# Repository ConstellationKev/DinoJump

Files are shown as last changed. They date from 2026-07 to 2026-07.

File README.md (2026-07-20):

# Dino Jump: Mechanical Dinosaur Game
See our demo video [here](https://youtu.be/Z2IjySYvM9o?si=r-w-ZcUsuN7d3cY8)

# Event Photos





## Zine:

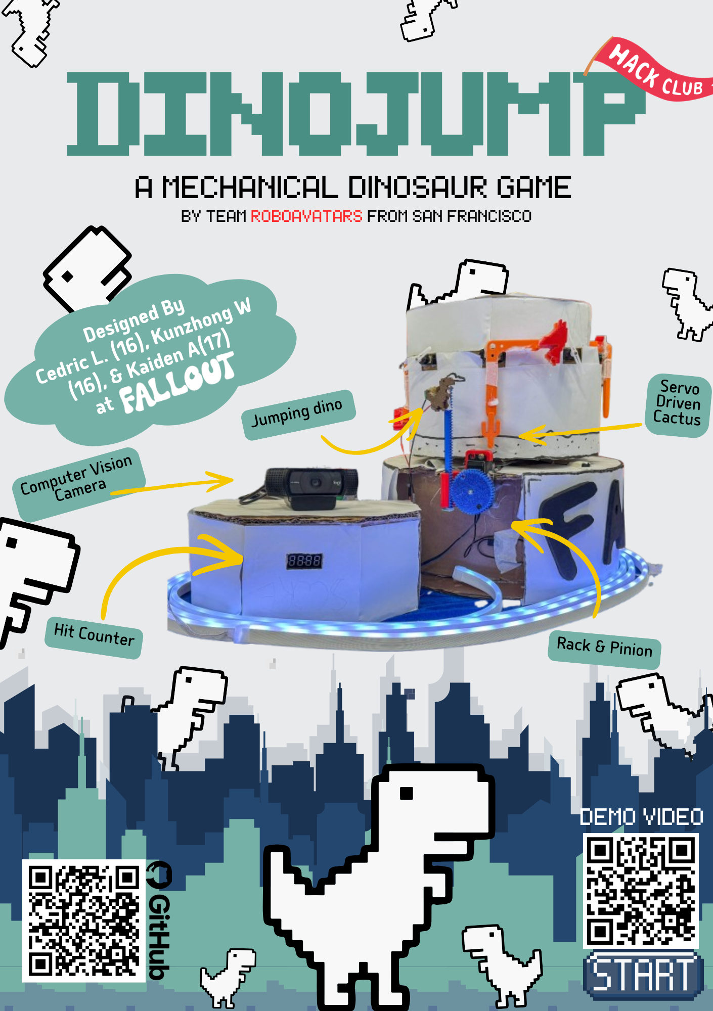
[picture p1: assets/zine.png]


## Why?
### It's 2026, the world has just ended shortly following the Fallout Hackathon...
Within weeks, Canned Wifi supplies have ran out. People have no choice but to the play the classic Chrome Dinosaur game that pops up without internet access.

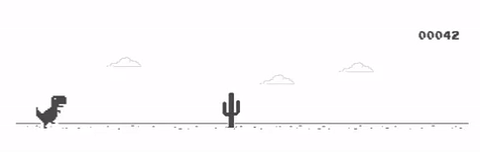
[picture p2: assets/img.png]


We wanted to focus on making a **mechanical version of the game** that relies on **hardware components and physical interaction** rather than heavy software. For this reason, we wanted the Dinosaur to physically interact with the obstacles.

Keeping in mind a focus on physicality (and to make the game more fun) the game is **controlled by a person's physical movement (Jumping/Standing/Crouching)**.

Also, the lack of stable wifi at the venue heavily inspired our idea.

## How?

### 1. The Obstacles:
- The Obstacles are mounted to a large circular disc (a Carousel) **powered directly by a small DC motor.**
- The motor **spins to send obstacles** to the Dinosaur.
- The obstacles are mounted to 4-8 servos, which **randomize the obstacles by either flipping to a** **Cactus, Bird, or nothing.**
- A **small limit switch mounted to the bottom of the carousel**, which brushes up against carefully placed foam bumps, **tells the obstacles when to randomize** their position.

### 2. The Dinosaur
- A **small rack and pinion** assembly moves the stationary Dinosaur up and down
- A small pin allows the dinosaur to **physically touch the obstacles**
- A limit switch pressed up against the Dinosaur **detects hits against the obstacles** when the Dinosaur is physically hit

### 3. Computer Vision
- Mediapipe detects the **position of body limbs**
- OpenCV **processes the camera input**
- **Serial connection** to an ESP32 controls the rack and pinion.

### 4. Electronics
- Since the Carousel is rotating on the base, **there can be no wires that are shared between the two.**
- **The Carousel**
  - The Carousel is powered by Quadruple AA battery pack that supplies 6V to the motor and servos.
  - We use a linear voltage regulator to step down to 3.3V for the ESP32.
  - The DC motor runs on a DRVAA33, and servos run on a PCA9685.
  - A limit switch localizes the position of the carousel to ensure that the obstacles randomize when not facing the user.
- **The Base**
  - The Base is powered by a 5V wall adapter.
  - An powers the rack and pinion, connected to another PCA9685.
  - ESP32 recieves Serial commands ("Standing", "Jumping", "Squatting").

## Assembly
- **You may assemble each component in any order**.
- ### The Base
  - Cut two 12in. diameter cardboard circles.
  - On one of the circles, mount the with zipties.
  - Build a central cylinder that is taller than 140mm.
  - Glue the circles to the ends of the cylinder.
  - Cut the top circle to mount the rack and pinion assembly as shown:
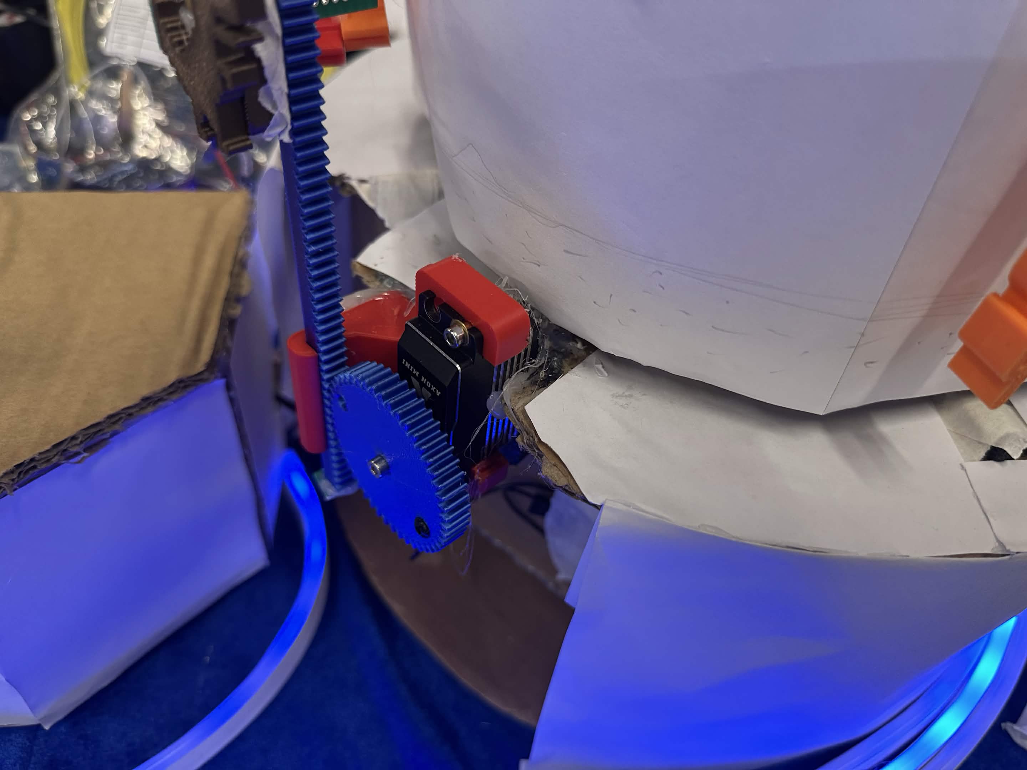
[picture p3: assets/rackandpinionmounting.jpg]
  
  - Attach 4 foam bumpers such that they hit the limit switch every 2 servos, as shown:
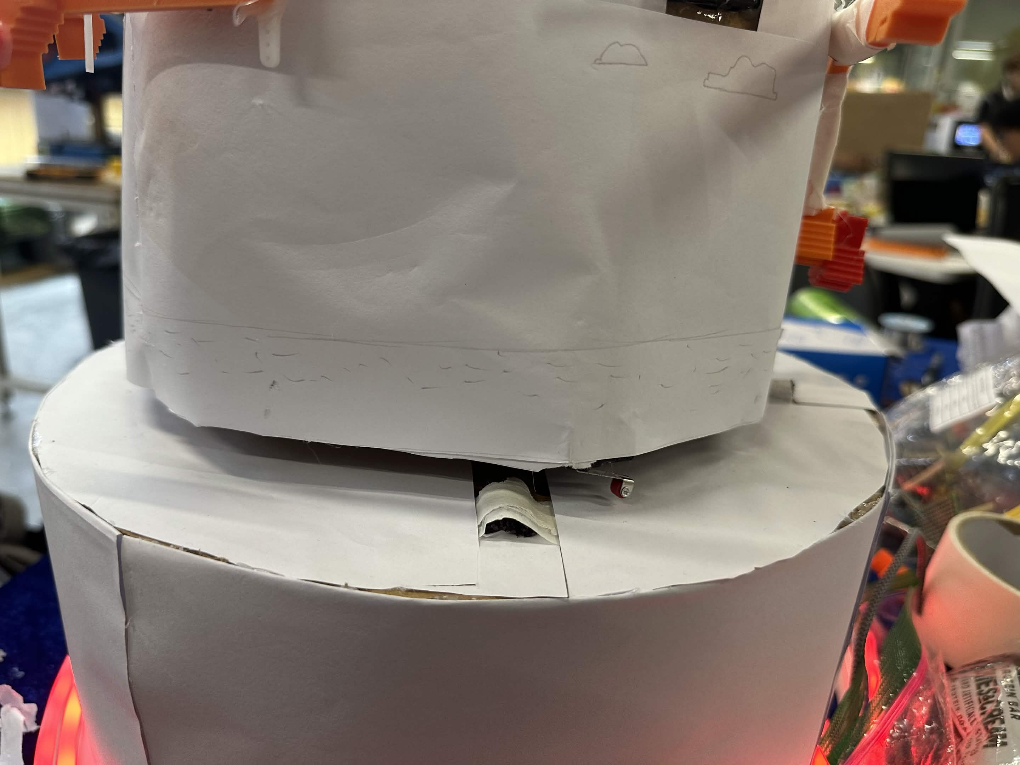
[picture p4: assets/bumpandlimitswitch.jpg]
  - 
- ### The Carousel
  - Cut 8 cardboard strips which are roughly 220mm by 110mm. Fold a 70mm section, followed by a 60mm section, a 30mm section, and another 60mm section. It should look like:

    | 70mm    | 60mm | 30mm | 60mm |
    |---------|------|----|------|
  - Fold the strips into trapezoids, with the 70mm and 30mm sides being parallel. Assemble as shown
  - Cut out slots for servos, as shown:
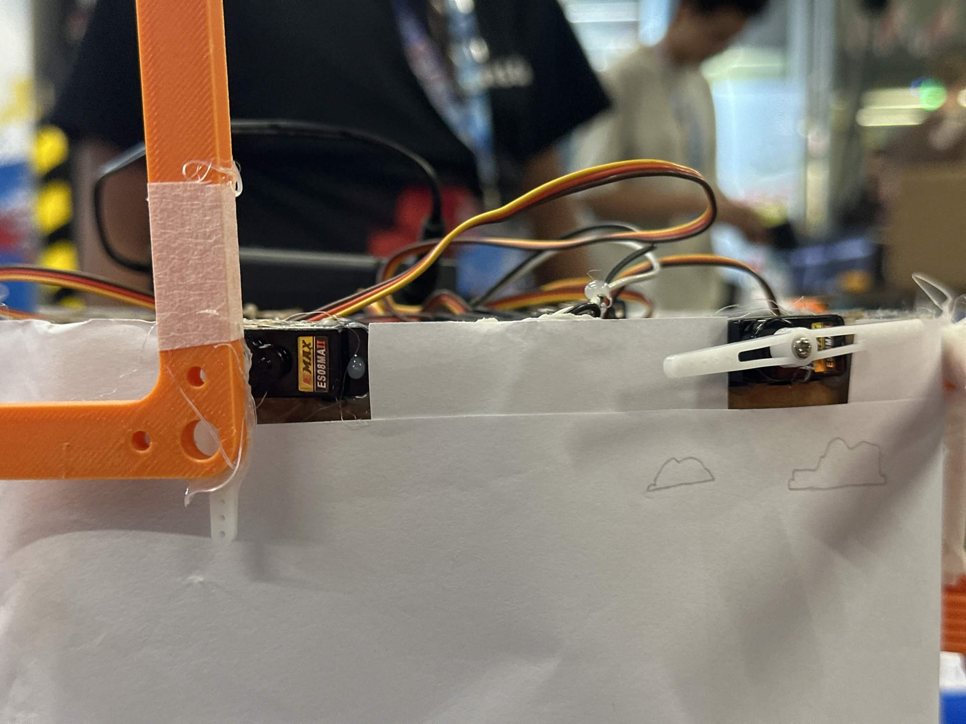
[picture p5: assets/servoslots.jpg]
  
  - Assemble the octagon with hot glue and tape. Take your time!
  - Attach the obstacles to the servos using the servo horn
  - Cut a circle roughly 10in. in diameter, it should be the same diameter as the octagon
  - Mount the motor and mount using zipties and M3 screws
  - Follow the wiring diagram (wire before final assembly)
  - Mount the circle and octagon with hot glue
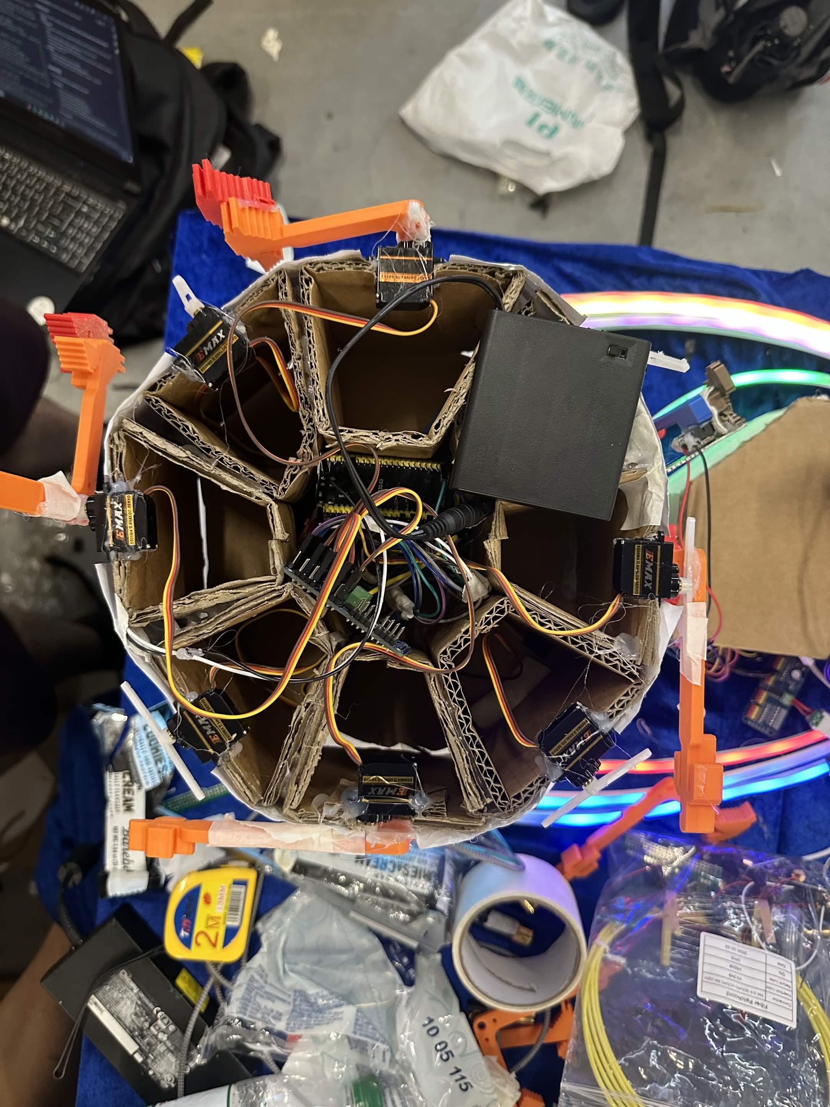
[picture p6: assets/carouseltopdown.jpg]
  

## Software
- Flash corresponding sketches to each ESP32 S3 using Arduino IDE
- If you do not get a serial output/input, try changing the USB CDC setting

## Usage
- Power the Base by plugging in the wall connector
- Start vision.py and follow on screen cailbration
- Position the 0 servo next to the limit switch bump
- Power the Carousel by turning on the battery

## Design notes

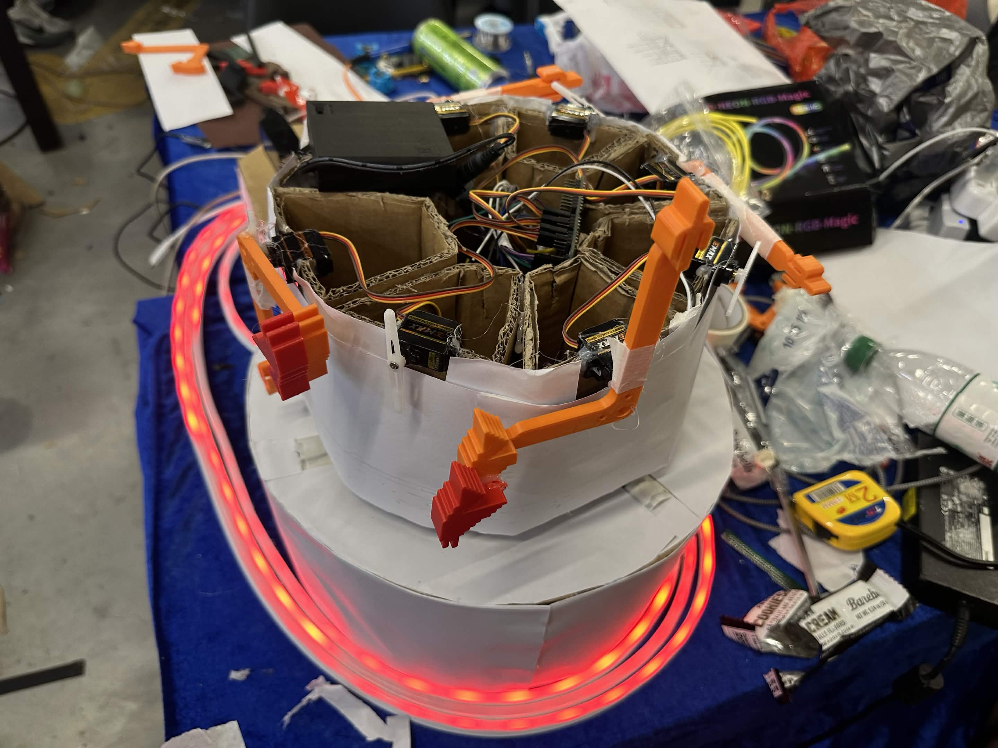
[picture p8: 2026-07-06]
assets/normalviewcarousel.jpg

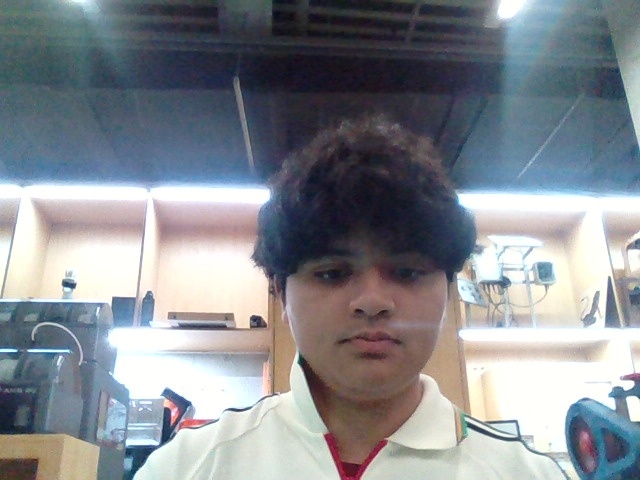
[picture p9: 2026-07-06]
firmware_base/image.jpg

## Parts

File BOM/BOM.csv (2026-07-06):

Material | Qty | Units | Buying Link (Accounts for quantity) | Cost (Accounts for shipping) | Notes
ESP32-S3 N16R8 Dev Board | 2 | Each | https://www.amazon.com/Hosyond-Development-Dual-Mode-Compatible-ESP32-S3-WROOM-1/dp/B0F5QCK6X5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 | $18.99
Quadruple AA Battery Pack 6V | 1 | Each | https://www.amazon.com/VWEICYY-Battery-Holder-housing-Leads/dp/B0DZWK2TNY?sp_csd=d2lkZ2V0TmFtZT1zcF9hdGY | $6.99
DRV8833 Motor Driver | 1 | Each | https://www.amazon.com/dp/B07S7Z8CFL/ref=twister_B07S5J1HGP?_encoding=UTF8&th=1 | $5.99
16-Channel 12-bit PWM/Servo Driver - PCA9685 | 2 | Each | https://www.microcenter.com/product/613661/adafruit-industries-16-channel-12-bit-pwm-servo-driver | $29.90
20 AWG Silicone Hookup Wires (2 Colors) | 1 | Wires | https://www.amazon.com/Silicone-Electrical-Core-Flexible-Strands/dp/B0B9JCXN9M/ | $5.88
Female DC Power adapter - 2.1mm jack to screw terminal block | 1 | Each | https://www.amazon.com/ALITOVE-100-240V-Replacement-Security-Raspberry/dp/B0BVHQKNS6/ | $9.99
5V 2A (2000mA) switching power supply - UL Listed | 1 | Each | Same as above ^ | $0.00 | Included in above price
Female DC Barrel Jack | 1 | Each | https://www.amazon.com/California-JOS-Breadboard-Friendly-Mounting-Female/dp/B09ZBN38FS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 | $6.99
Low Profile Servo | 1 | Servos | https://www.amazon.com/Deegoo-FPV-Servo-MG995-Metal-Gear/dp/B0D7M3BBL2 | $13.98
ES08MAII E-MAX Analog Micro Servo | 4 | Servos | https://www.amazon.com/dp/B07KYK9N1G?lv=shuf&channelId=500&plpRedirect=mhFallback&th=1 | $39.99 | Expensive or cheap both works; use cheap to save money. Also we got this at HJB and it was SO MUCH CHEAPER (10RMB each compared to 10USD each)
M2.5 Screws + Nuts Kit | 1 | Each | https://www.amazon.com/binifiMux-280pcs-Button-Socket-Assortment/dp/B09CPDVYB7/ | $9.99
M2 Screws + Nuts Kit | 1 | Each | https://www.amazon.com/QOOSIKICC-Assortment-Socket-Washers-Machine/dp/B0DDXZH9L2/ | $7.58
M4 Screws + Nuts Kit | 1 | Each | https://www.amazon.com/Machine-Screws-Countersunk-Phillips-Assortment/dp/B0CCPJTVL1 | $6.48
Soldering Kit | 1 | Each | https://www.amazon.com/Soldering-soldering-solder-adjustable-temperature/dp/B09DY7CCW5/ | $9.99
Jumper Wires Assortment | 1 | Each | https://www.amazon.com/Elegoo-EL-CP-004-Multicolored-Breadboard-arduino/dp/B01EV70C78 | $6.98 | Self-sourced, I already own this so I don't need extra funding for this.
AMS1117 Voltage Regulator | 1 | Each | https://www.amazon.com/VKLSVAN-AMS1117-3-3V-Converter-Voltage-Regulator/dp/B0DPMQXWMS?nsdOptOutParam=true | $5.96
GA25Y-370 Motor-47.9 | 1 | Each | https://www.amazon.com/25GA-370-Reduction-Geared-Electronic-400RPM/dp/B07JGWXSHF | $12.43 | Or any webcam of your choice, labtop/compiter webcam also works
Logitech C920 Webcam | 1 | Each | https://www.amazon.com/Logitech-Widescreen-Calling-Recording-Desktop/dp/B006JH8T3S | $68.00
TM1637 4-Digit Display | 1 | Each | https://www.amazon.com/DIYables-4-Digit-7-Segment-Display-Raspberry/dp/B0BXKLZJMV | $5.99
Cardboard | 1 | Board | N/A | $0.00
Hot Glue Kit | 1 | Each | https://www.amazon.com/Krightlink-Sticks-School-Crafts-Repairs/dp/B0BC878ZRG | $8.99
Limit Switches | 2 | Each | https://www.amazon.com/HiLetgo-KW12-3-Roller-Switch-Normally/dp/B07X142VGC | $5.99
Magnets 6mm | 2 | Pairs | https://www.amazon.com/Magnets-Refrigerator-Cylinder-Whiteboard-Miniature/dp/B0936M3WPK | $4.99
Foam | 1 | Block | N/A | $0.00
Rack and Pinion 3D Part | 1 | Each | N/A | $0.02
Obstacles 3D Part | 4 | Each | N/A | $0.47
Motor Mount 3D Part | 1 | Each | N/A | $0.77
Dinosaur 3D Part | 1 | Each | N/A | $0.13
AA Batteries | 4 | Each | amazon.com/AmazonBasics-Performance-Alkaline-Batteries-8-Pack/dp/B00O869KJE/ref=sr_1_3?crid=21ZB6L8Y1KM0Q&dib=eyJ2IjoiMSJ9.qezp8kXthZdyOBn254AAdiHAMmzXcHLZXWFYbgOx69AsDOUuSlgEUCvC4RzXWH5pQL8X_oJBTllFXSrfwQ7rw9NtlTY5eaAw37qBd06A8L5TseoImHSYmPRshfoVNVHUZAKYJ5a7R2QoNg42nsfvws1XVmeLXh5D-VpWx6-6GZwQKfoSbI8UcDbxxxdEjErTgjrtv4kW8xBEbacESqa2y5I4J9XRK2lRNKYTnBcUT4an80o3jUrB-QKVBCfdaEjHsmL5InILFzfC9juOh9kNUUAl3002ga5K2L38MbX2hn4.mP9y-W-w3PzfKWmnAqugdhXhgWxFmitU8cyaP9EEUgU&dib_tag=se&keywords=AA+batteries&qid=1783315609&rdc=1&sprefix=aa+batter%2Caps%2C414&sr=8-3 | $6.49
Taxes (in Fremont, California) | N/A | N/A | N/A | $28.51 | I don't need extra funding for this, I can pay this.
 |  |  | Total Cost: | $328.46
 |  |  | Note: Everything is bought with Amazon and Microcenter which has free shipping

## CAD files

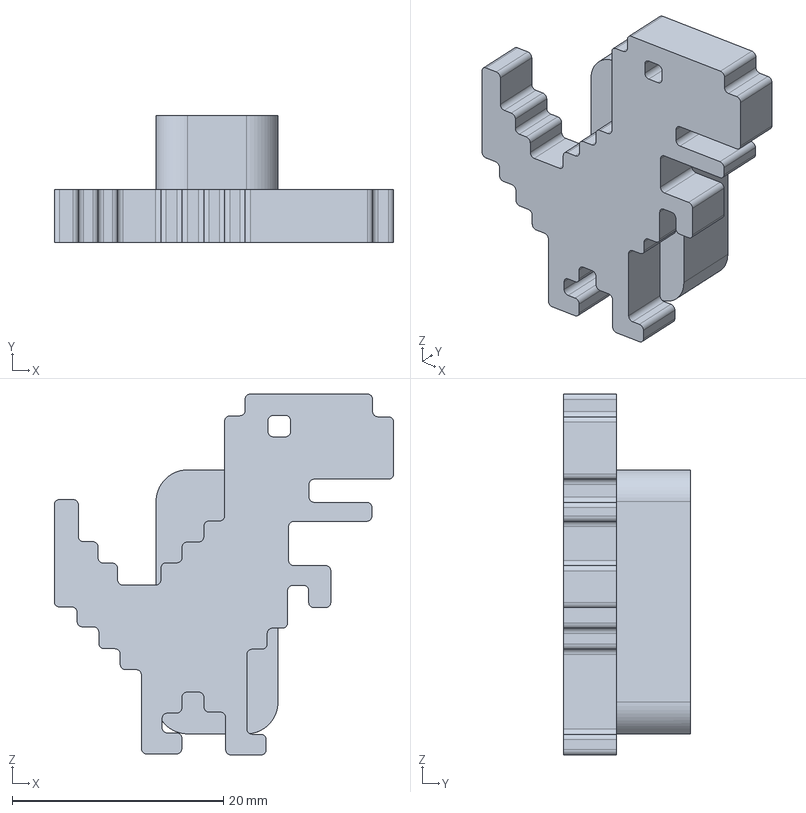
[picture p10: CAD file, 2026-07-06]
CAD/dinosaur assembly - Part 4.step
32.1 x 12.0 x 34.2 mm

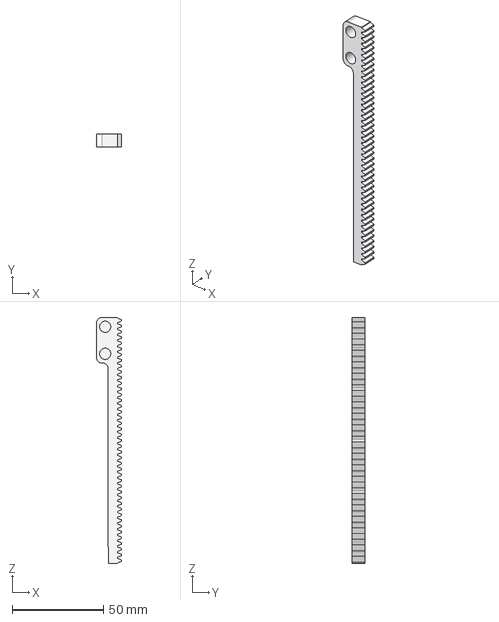
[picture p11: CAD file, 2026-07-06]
CAD/dinosaur assembly - Part 1.step
13.7 x 7.00 x 135.1 mm

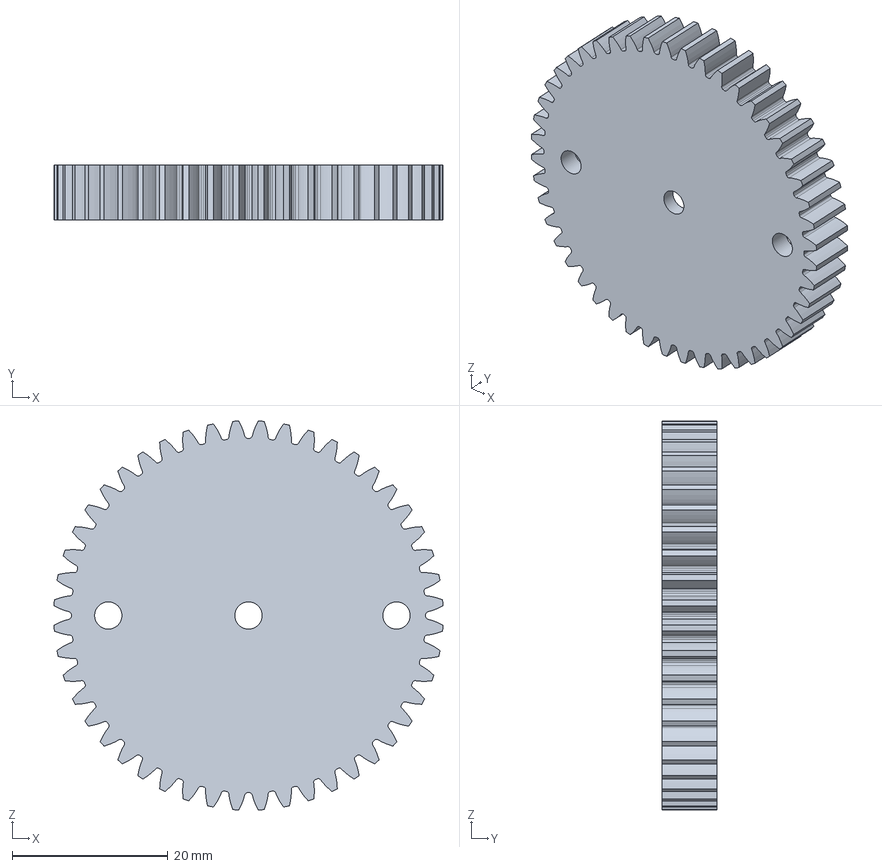
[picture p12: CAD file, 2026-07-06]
CAD/dinosaur assembly - Spur gear (48 teeth).step
49.9 x 7.00 x 49.9 mm

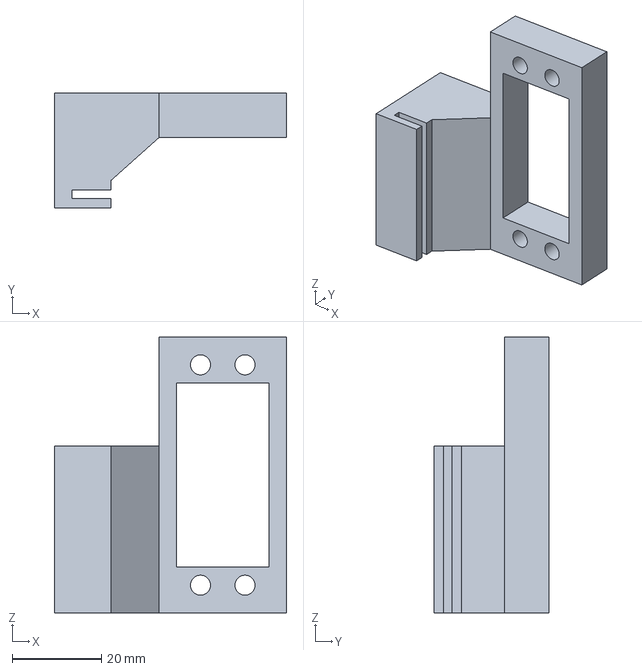
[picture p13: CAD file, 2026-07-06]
CAD/dinosaur assembly - Part 3.step
52.2 x 25.7 x 62.0 mm

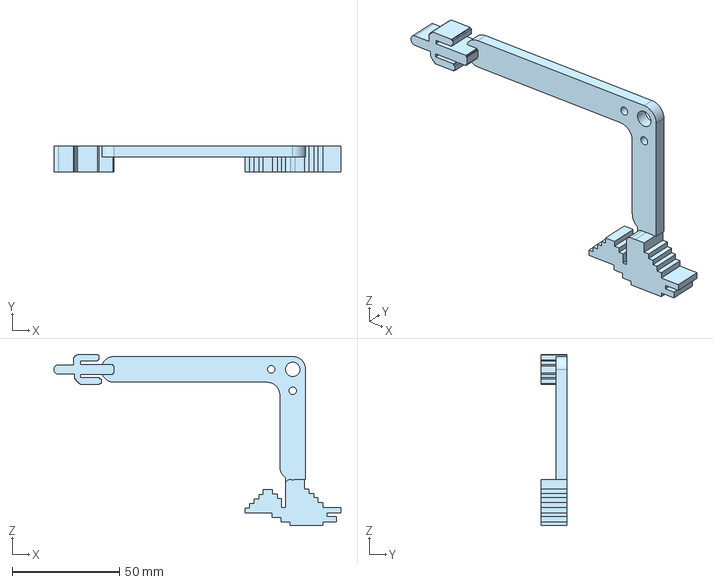
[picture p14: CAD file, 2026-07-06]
CAD/small cactus - Part 1.step
133.8 x 12.0 x 79.9 mm

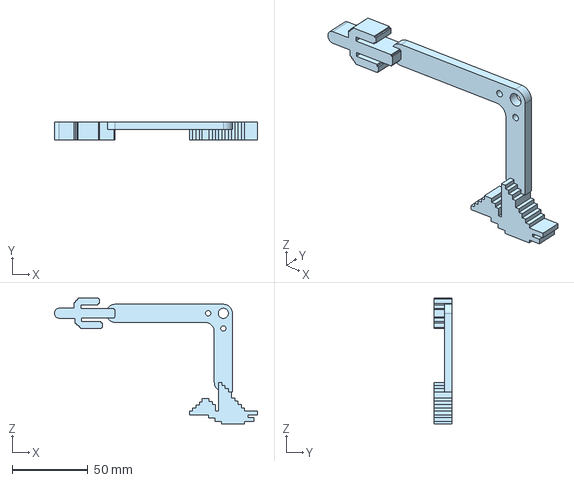
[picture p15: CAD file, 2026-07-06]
CAD/big cactus - Part 1.step
133.8 x 12.0 x 82.9 mm

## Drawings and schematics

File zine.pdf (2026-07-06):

d

I

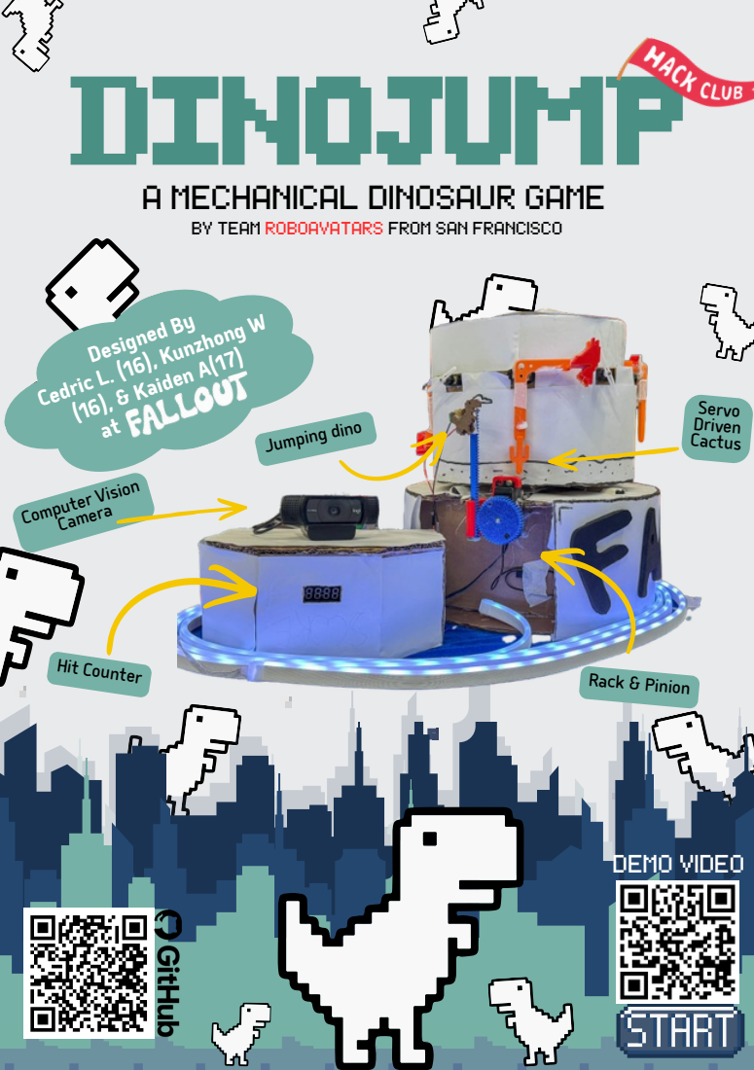
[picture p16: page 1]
Jumping dino; Hit Counter; Computer Vision Camera; Designed By Cedric L. (16), Kunzhong W (16), & Kaiden A(17); MEC; HANI; CAL; DINOS; AUR; GAME; Rack & Pinion; Servo Driven Cactus; DEMO VIDEO

BY TEAM ROBOAVATARS FROM SAN FRANCISCO

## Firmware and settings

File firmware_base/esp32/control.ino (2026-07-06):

#include <Wire.h>
#include <Adafruit_PWMServoDriver.h>
#include <TM1637Display.h>


#define LIMIT_SWITCH 47
#define BUTTON_PIN 12

#define CLK 40
#define DIO 41
TM1637Display display(CLK, DIO);

// Create the driver object (default address 0x40)
Adafruit_PWMServoDriver pca = Adafruit_PWMServoDriver(0x40);

// Servo parameters (adjust these if your servo doesn't stop or reach full speed)
const int SERVO_FREQ = 50;  // Analog servos run at 50Hz (20ms period)

int SCORE = 0;

const int AXON_STANDING = 460;
const int AXON_JUMPING = 102;
const int AXON_SQUATTING = 602;
const int CONTINU = 1;

const int FLAP_UP = 50;
const int FLAP_DOWN = 70;

String state = "Standing";

void setup() {
  pinMode(LIMIT_SWITCH, INPUT_PULLUP);
  pinMode(BUTTON_PIN, INPUT_PULLUP); 

  Serial.begin(115200);
  while (!Serial) {
    delay(10); 
  }
  Serial.println("\nESP32 Serial Initialized.");

  pca.begin();
  pca.setPWMFreq(SERVO_FREQ);
  delay(10);

  display.setBrightness(0x0f);

}

int jumpPos;
int stateTime;
double GRAVITY = 0.005;
double VELOCITY = 1.47;
bool hit = false;

bool flappy = true; // channge this variable someway ygs got this

void loop() {
    // for (int i = 0; i < 10000; i++) {
  display.showNumberDec(SCORE, false); // (number, leading zeros)
    //   delay(100); // Wait 100 milliseconds between counts
    // }
  Serial.println(digitalRead(LIMIT_SWITCH));

  int buttonState = digitalRead(BUTTON_PIN);
  if (buttonState == LOW) { 
    SCORE = 0;
  }
  
  if (digitalRead(LIMIT_SWITCH)==CONTINU) {
    hit = false;
    String inputState;
    if (Serial.available() > 0) {
      String incomingMessage = Serial.readStringUntil('\n');
      incomingMessage.trim(); 
        
      Serial.print("Echo: ");
      Serial.println(incomingMessage);
      inputState = incomingMessage;
    }
    int curTime = millis();

    // pca.setPWM(4, 0, AXON_MIN); 
    // delay(2000);

    // pca.setPWM(4, 0, AXON_MAX); 
    // delay(2000);

    Serial.println(state);
    if (!flappy) {
      if (state == "Standing") {
        pca.setPWM(4,0,AXON_STANDING);
        // delay(100);
        if (inputState == "Jumping" || inputState == "Squatting") {
          state = inputState;
          stateTime = curTime;
        }
      }
      else if (state == "Jumping") {
        int jumpPos = (int) (AXON_STANDING + 0.5 * GRAVITY * (curTime - stateTime) * (curTime - stateTime) + -VELOCITY * (curTime - stateTime));
        if (jumpPos < AXON_JUMPING) {
          jumpPos = AXON_JUMPING;
        }
        if (jumpPos > AXON_STANDING) {
          jumpPos = AXON_STANDING;
          state = "Standing";
        }
        pca.setPWM(4,0,jumpPos);
        Serial.println(jumpPos);
        // delay(50);
      }
      else if (state == "Squatting") {
        pca.setPWM(4,0,AXON_SQUATTING);
        if (inputState == "Jumping" || inputState == "Standing") {
          state = inputState;
          stateTime = curTime;
        }
        // delay(100);
      }
    } else {
        if (state == "Jumping") {
          jumpPos -= FLAP_UP;
          delay(100);
        }
        else {
          jumpPos += FLAP_DOWN; 
        }

        if (jumpPos > 460) {
          jumpPos = 460; 
        }
        else if (jumpPos < 102) {
          jumpPos = 102; 
        }
        

        pca.setPWM(4,0,jumpPos);
        Serial.println(jumpPos);
        // delay(50);
    }
  }
  else {
    Serial.println("Hit");
    if (!hit) {
      SCORE++;
      hit = true;
    }

  }
}

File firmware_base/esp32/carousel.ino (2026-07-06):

#include <Wire.h>
#include <Adafruit_NeoPixel.h>
#include <Adafruit_PWMServoDriver.h>
#define LED_PIN     48 
#define NUM_PIXELS   1 

#define SWITCH_PIN 47

Adafruit_NeoPixel rgbLed(NUM_PIXELS, LED_PIN, NEO_GRB + NEO_KHZ800);
Adafruit_PWMServoDriver pca = Adafruit_PWMServoDriver(0x40);

const int SDA_PIN = 8;
const int SCL_PIN = 9;
const int SERVO_FREQ = 50;
const int STOP_PULSE = 372;
const int MAX_CW = 205;
const int MAX_CCW = 540;
const int SERVOMIN = 150;
const int SERVOMAX = 600;
const int E_MIN = 100;//102
const int E_MAX = 520;//512

const int E_CACTUS = 102;
const int E_BIRD = 512;
const int E_ = 307;

const int AIN1_PIN = 4;
const int AIN2_PIN = 5;
const int SLEEP_PIN = 7;

int state = 0;

void setup() {
  Serial.begin(115200);
  while (!Serial) {
    delay(10); 
  }
  Serial.println("\nESP32 Serial Initialized.");
  Wire.begin(SDA_PIN, SCL_PIN);
  pca.begin();
  pca.setPWMFreq(SERVO_FREQ);
  delay(10);
  rgbLed.begin();
  randomSeed(analogRead(0));

  pinMode(AIN1_PIN, OUTPUT);
  pinMode(AIN2_PIN, OUTPUT);
  pinMode(SLEEP_PIN, OUTPUT);

  digitalWrite(AIN1_PIN, LOW);
  digitalWrite(AIN2_PIN, LOW);

  digitalWrite(SLEEP_PIN, HIGH);

  pinMode(SWITCH_PIN, INPUT_PULLUP);

}

const int DELAY = 500;
int startPos = 0;
int motorSpeed =85;
int pos = -1;
int perTime;
bool pressed;

void loop() {
  int curTime = millis();
  motorF(motorSpeed);
  Serial.println(digitalRead(SWITCH_PIN));
  if (!pressed && (curTime - perTime > 2700 || (digitalRead(SWITCH_PIN) == HIGH && curTime - perTime > 100))) {
    pressed = true;
    perTime = curTime;
  }
  if (pressed) {
    pos = startPos%8;
    int r = random(3);
    if (r == 0) {
      pca.setPWM(pos,0,E_CACTUS);
    }
    else if (r == 1) {
      pca.setPWM(pos,0,E_BIRD);
    }
    else {
      pca.setPWM(pos,0,E_);
    } 
    r = random(3);
    if (r == 0) {
      pca.setPWM((startPos+1)%8,0,E_CACTUS);
    }
    else if (r == 1) {
      pca.setPWM((startPos+1)%8,0,E_BIRD);
    }
    else {
      pca.setPWM((startPos+1)%8,0,E_);
    }
    startPos += 2;
    delay(450);
    pressed = false;
  }
}

void motorF(int speed) {
  analogWrite(AIN2_PIN, 0);
  analogWrite(AIN1_PIN, speed);
}

void motorR(int speed) {
  analogWrite(AIN1_PIN, speed);
  analogWrite(AIN2_PIN, 0);
}

void motorS() {
  analogWrite(AIN2_PIN, 0);
  analogWrite(AIN1_PIN, 0);
}
